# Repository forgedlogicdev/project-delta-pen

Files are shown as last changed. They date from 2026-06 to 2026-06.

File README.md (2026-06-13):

# Project Delta Pen (DP-1)
> **STATUS: ACTIVE R&D**  
> High-precision, ergonomic, motorized coaxial TIG filler wire feeder powered by RP2040 and closed-loop force sensing feedback.

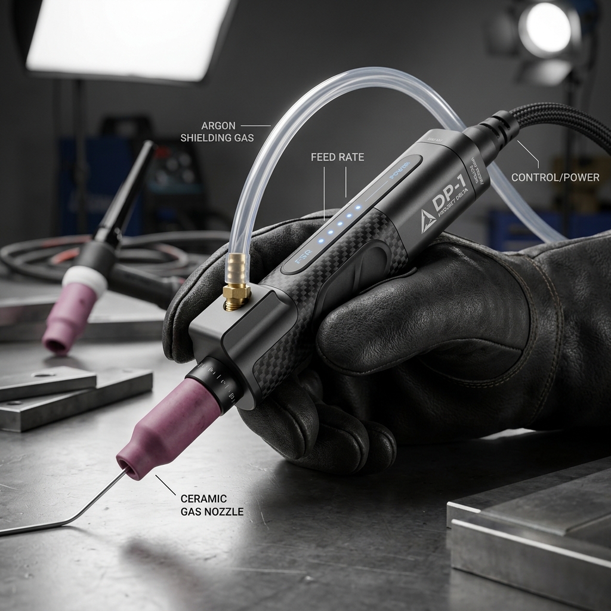
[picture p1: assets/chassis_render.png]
Project Delta Pen (DP-1) Mockup


---

## System Overview

Project Delta Pen (DP-1) is a handheld, motorized welding wire feeder designed to streamline TIG wire deposition. Featuring a lightweight, coaxial wire feed path and an integrated Force Sensitive Resistor (FSR) index grip, the DP-1 responds dynamically to user finger pressure, outputting precise wire feed rates directly into the weld puddle.

```mermaid
graph LR
    User(["User Finger Force"]) -->|Pressure| FSR["FSR Strip GPIO 26"]
    FSR -->|Analog Signal| MCU["RP2040 Microcontroller"]
    Switch["Pulse-Dab Switch GPIO 15"] -->|Hardware Interrupt| MCU
    MCU -->|PWM/Pulse| Driver["TMC2209 Driver"]
    Driver -->|Torque| Motor["NEMA 8 Motor"]
    Motor -->|Direct Drive| Pinch["Pinch Wheel Mechanism"]
    Pinch -->|Coaxial Path| Wire["TIG Filler Wire"]
```

---

## Directory Structure

```text
peaceful-franklin/
├── .gitattributes          # LFS tracking configurations
├── .gitignore              # Dependency and build exclusions
├── LICENSE                 # MIT Open Source License
├── README.md               # High-level architecture and mechanical logic
├── BUILD.md                # Component sourcing and assembly guide
├── docs/                   # Detailed technical breakdowns
│   ├── specs.md            # Hardware tolerances and power curves
│   └── user_manual.md      # Calibrations and operation guide
├── cad/                    # Parametric CAD models
│   ├── chassis.scad        # Ergonomic handheld shell design
│   └── drive_gear.scad     # V-groove pinch wheel models
├── firmware/               # Microcontroller firmware
│   └── main.py             # CircuitPython RP2040 control loop
└── assets/                 # Schematics and visual guides
    ├── chassis_render.png  # High-fidelity industrial design mockup
    └── connection_map.png  # Wiring diagrams
```

---

## Mechanical Logic

The DP-1's mechanical efficiency relies on two primary innovations: its **coaxial wire feed path** and the **direct-drive pinch mechanism**.

```
             [ NEMA 8 Motor ]
                   │
                   ▼ (Direct Drive shaft)
           [ V-Groove Wheel ] <--- (Pinch Force) ---> [ Bearing Tensioner ]
                   │
                   ▼
===================[ Coaxial Wire Feed Guide Tube ]===================
==== Wire ==========================================================>
```

### 1. Coaxial Wire Feed
Traditional motorized wire feeders feed wire off-axis, creating rotational torque that causes hand fatigue during long welding runs. The DP-1 routes the filler wire directly through the centerline axis of the pen-like body. The wire exits the rear, travels through a flexible PTFE guide sheath, passes through the motor chassis, and exits straight out of the nozzle. This eliminates off-axis drag and maintains optimal ergonomics.

### 2. Direct-Drive Pinch Mechanism
To feed 1.6mm to 3.2mm aluminum or stainless steel wire without slipping, the chassis houses a high-torque **NEMA 8 stepper motor** mated to a custom-grooved **V-Groove drive wheel**. A secondary spring-loaded guide bearing pinches the wire against the V-groove. This direct coupling ensures zero backlash, high driving torque, and instant startup/stop response.

---

## Firmware Overview

The system runs a modular control loop implemented in CircuitPython on the RP2040. Features include:
* **Dynamic FSR Scaling**: Analog pressure mapping to feed rate.
* **Safety Pulse-Dab Switch**: Dedicated GPIO hardware interrupt to pause, retract, or pulse feed instantly, preventing runaway feeding.

For source details, see [firmware/main.py](file:///home/_____/Documents/antigravity/peaceful-franklin/firmware/main.py).

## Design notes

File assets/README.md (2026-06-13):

# Project Delta Pen Assets Directory
This folder contains graphical resources, wiring diagrams, and high-resolution schematics for the DP-1 hardware.

## Expected Files
* `connection_map.png`: Main RP2040 and TMC2209 wiring schematic.
* `chassis_render.png`: 3D-render of the assembled coaxial handle shell.

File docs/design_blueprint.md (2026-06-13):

# Project Delta Pen (DP-1) Engineering & Design Blueprint
> **Version**: 1.1.0  
> **Classification**: Technical Design Proposal / R&D Guide  
> **Authors**: Lead Systems Architect & Engineering Team  

This document serves as the high-level structural, mechanical, and electrical blueprint for the **Project Delta Pen (DP-1)**. It addresses the engineering challenges of miniaturized, coaxial wire-feeding, structural thermodynamics, and force-sensitive control loops.

---

## 1. Ergonomic & Structural Architecture

The primary design challenge of the DP-1 is maintaining hand comfort over long duty cycles while carrying an active actuator (NEMA 8 stepper motor).

```
                     [ CENTER OF MASS ]
                             ▼
  ┌───────────────────────────────────┬──────────────┐
  │         ERGO GRIP SECTION         │ MOTOR BLOCK  │ ===> Rear Harness
  │  (Lightweight SLS Nylon / Carbon) │ (6061 Alum)  │      (Power & Gas)
  └───────────────────────────────────┴──────────────┘
  ◄────────────── 100mm ─────────────►◄──── 20mm ────►
```

### Material Selection Comparison
We evaluated three primary fabrication paths for the pen housing:

| Fabrication Method | Recommended Materials | Tensile Strength | Thermal Conductivity | Pro/Con Analysis |
|---|---|---|---|---|
| **SLS 3D Printing (Recommended)** | Nylon PA12 / Carbon-Filled | ~48 MPa | Low (~0.25 W/m·K) | **Pros**: Excellent weight distribution, complex internal wire routing. <br>**Cons**: Poor heat dissipation. |
| **CNC Machining** | 6061-T6 Anodized Aluminum | ~310 MPa | High (~167 W/m·K) | **Pros**: Extreme durability, acts as a heatsink. <br>**Cons**: Increases hand weight (fatigue), requires electrical isolation. |
| **FDM 3D Printing** | PETG / Polycarbonate (PC) | ~60 MPa | Low | **Pros**: Fast prototyping, low cost. <br>**Cons**: Anisotropic strength (weak layer bonding under wire tension). |

### Engineering Decision
* **Chassis Body**: Select **SLS Nylon PA12** for its structural density, toughness, and thermal isolation from the welding environment.
* **Motor & Tension Block**: Select CNC machined **6061-T6 Aluminum**. This block mounts directly to the NEMA 8 motor to act as a heat-sink, protecting the user's hand from motor-coil heat.

---

## 2. Mechanical Drive & Torque Physics

Feeding rigid filler wire (such as 2.4mm ER70S-6 steel or ER4043 aluminum) requires significant linear push force without buckling or crushing the wire.

```
       Force (Idler Pressure)
              │
              ▼
   [ U-Groove Idler Bearing ]
  ═════════════════════════════  ◄─── Filler Wire
   [ V-Groove Drive Gear ]
              ▲
              │
         Motor Torque
```

### Torque Calculations
To calculate the minimum holding torque required for the stepper motor ($T_{motor}$):
$$T_{motor} = F_{push} \times r_{drive}$$

Where:
* $F_{push}$ = Linear force required to feed wire through the PTFE tube (typically 12 N to 20 N depending on bends).
* $r_{drive}$ = Radius of the drive wheel ($6\text{ mm} = 0.006\text{ m}$).

$$T_{motor} = 20\text{ N} \times 0.006\text{ m} = 0.12\text{ N·m} = 12\text{ N·cm}$$

* **Motor Specification**: A standard NEMA 8 stepper motor (e.g., 20mm body) provides approximately $1.6\text{ to }3.0\text{ N·cm}$ holding torque. This is **insufficient** for direct drive under heavy friction.
* **Solution**: 
  1. Use a **geared NEMA 8** (e.g., 5:1 planetary gearbox) to multiply torque to $15\text{ N·cm}$ while maintaining low weight.
  2. Implement ultra-low friction **polished PTFE liners** (1.8mm ID for 1.6mm wire) to keep $F_{push}$ under $4\text{ N}$, which keeps direct drive viable.

---

## 3. Electronics & Driver Configuration

The **TMC2209** stepper driver must be software-configured via UART or physical hardware pins to balance noise, heat, and torque.

### StealthChop™ vs. SpreadCycle™
* **StealthChop (Quiet)**: Reduces motor noise to near silent. However, high-current peaks can cause step losses when the filler wire encounters friction.
* **SpreadCycle (High Torque)**: Offers superior torque dynamics and speed control, but introduces standard stepper motor whine.
* **Hybrid Configuration (Recommended)**: Set the threshold velocity in firmware. Below 20 mm/s (normal welding speeds), run StealthChop for silent operation. Above 20 mm/s, transition to SpreadCycle for peak driving torque.

### Thermal Dissipation
Operating a NEMA 8 motor close to its current limit (0.6A) inside a hand-held plastic pen causes heat accumulation. 
* Set motor current limit ($I_{rms}$) to **70% of rated capacity** ($0.4A$) in the driver settings.
* Implement an auto-standby power down: if the FSR has not registered force for 5 seconds, cut driver coil current to **10%** to prevent pen heat buildup.

---

## 4. Force-Sensitive Control Loop

A simple linear mapping of pressure to speed results in jerky wire feeding. The control loop must implement smoothing and threshold curves.

```
 Feed Rate (mm/s)
   │
120│                                  / (Exponential ramp)
   │                                 /
   │                                /
   │                       ________/
  0│───────────────────────
   └───[Deadzone]───────────► FSR ADC Value (0-65535)
     0 - 8000            60000
```

### Proportional-Derivative (PD) Signal Smoothing
The firmware reads the FSR ADC value and processes it using a low-pass filter (Exponential Moving Average) to prevent jitter:

$$V_{smooth} = \alpha \cdot V_{raw} + (1 - \alpha) \cdot V_{prev}$$

Where $\alpha = 0.15$ provides clean damping without noticeable input lag.

### Safety State Machine
The safety interrupt must follow a strict non-blocking hardware design:

```
  ┌──────────────┐      FSR Squeezed      ┌──────────────┐
  │  Idle State  ├───────────────────────►│ Feeding State│
  └──────▲───────┘                        └──────┬───────┘
         │                                       │
         │          Pulse-Dab Pressed            │
         └───────────────────────────────────────┘
```
When the `Pulse-Dab` switch is closed (pull-up pulled low), the RP2040 triggers an immediate interrupt, disabling the `EN` pin of the TMC2209 and ignoring FSR values until the switch is reset.

---

## 5. Welding Gas & Arc Integration

Shielding gas (Argon) must flow coaxially to shield the weld puddle from atmospheric contamination.

* **Gas Seal**: The shielding gas channel runs parallel to the wire feeding channel. It exits through internal gas diffusers in the front housing to create laminar flow.
* **Heat Shielding**: The ceramic gas cup (typically Size 6 or 8) is threaded onto a custom brass gas lens adapter. This lens isolates the printed plastic pen chassis from the high heat of the tungsten electrode.

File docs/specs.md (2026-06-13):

# Project Delta Pen (DP-1) Technical Specifications
> **Revision: 1.0.2**

This document details the engineering limits, electrical characteristics, and force sensor curves for the DP-1.

---

## 1. Physical Dimensions & Weights
* **Total Length (Chassis Only)**: 120 mm
* **Grip Diameter**: 14 mm to 18 mm (ergonomic taper)
* **Dry Weight**: 85g (excluding cable harness and stepper motor)
* **Total Operating Weight**: 142g (with NEMA 8 motor attached)

---

## 2. Stepper Actuation Parameters
* **Motor Type**: NEMA 8 Stepper (Dual Phase, bipolar)
* **Rated Current**: 0.6A per phase
* **Step Angle**: 1.8° per step (200 full steps per revolution)
* **Microstepping**: 1/16 microstepping configured on TMC2209 driver (3200 steps/rev)
* **Wire Feed Velocity Range**: 5 mm/s to 120 mm/s (controlled dynamically via FSR)

---

## 3. FSR Pressure Mapping Curve
The Interlink FSR 402 strip input is read through a 10-bit or 12-bit ADC on the RP2040. The force response follows an exponential curve:

| Applied Force (N) | Resistance (Ω) | ADC Voltage (V, 3.3V Ref) | Feed Rate (mm/s) |
|---|---|---|---|
| < 0.2 N | > 1 MΩ (Open) | < 0.15 V | 0 (Idle) |
| 0.5 N | ~ 10 kΩ | ~ 1.10 V | 10 mm/s |
| 2.0 N | ~ 2 kΩ | ~ 2.50 V | 45 mm/s |
| > 10.0 N | < 1 kΩ (Sat) | ~ 3.10 V | 120 mm/s |

---

## 4. Electrical Connections

```
    [RP2040 GPIO]                     [TMC2209 Driver]
    GP2 (Step) ──────────────────────► STEP
    GP3 (Dir)  ──────────────────────► DIR
    GP4 (En)   ──────────────────────► EN (Active Low)
    3.3V OUT   ───────┬──────────────► VDD (Logic)
                      │
                   [FSR]
                      │
    GP26 (ADC0) ◄─────┴───[10kΩ Pulldown]───► GND
```

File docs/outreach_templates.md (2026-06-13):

# Project Delta Pen (DP-1) Outreach Email Templates
> **Classification: External Communication & Marketing Briefs**

This document tracks outreach templates (in both plain text and styled HTML format) used for pitching the DP-1 technology.

---

## 1. Styled HTML Templates
HTML files are fully styled with embedded images, buttons, and custom layout tables:

*   **[docs/adafruit_pitch.html](file:///home/_____/Documents/antigravity/peaceful-franklin/docs/adafruit_pitch.html)**: Styled pitch for Adafruit featuring the RP2040 Silicon and CircuitPython stack.
*   **[docs/ck_pitch.html](file:///home/_____/Documents/antigravity/peaceful-franklin/docs/ck_pitch.html)**: Styled B2B proposal for CK Worldwide featuring the physical mockup render and engineering specifications.

---

## 2. Plain Text Outreach Emails

### Pitch 1: Adafruit (support@adafruit.com)
```text
Subject: Project Showcase: Motorized Coaxial TIG Welding Pen (Powered by RP2040 & CircuitPython)

Hi Adafruit Team,

I wanted to share a project I've been developing that applies Adafruit's favorite ecosystem—the RP2040 and CircuitPython—directly to industrial metal fabrication. 

It’s called Project Delta Pen (DP-1): an ergonomic, motorized coaxial TIG welding wire feeder. 

The pen uses an FSR strip on the index grip to dynamically map finger force to stepper motor feed speed, letting welders deposit filler metal with high precision. It is driven by a TMC2209 silent stepper driver and is powered entirely by CircuitPython on the RP2040. 

I’ve engineered a safety halt state machine using hardware interrupts on the RP2040 to guarantee instant feed stops, preventing wire overrun in industrial conditions.

Here is the GitHub repository detailing the OpenSCAD chassis files, build sheets, and current control loop:
https://github.com/forgedlogicdev/project-delta-pen

I’d love to know if this is something you would be interested in featuring on the Adafruit blog, or if you'd be open to a quick chat about optimizing FSR input conditioning.

Best regards,
ForgedLogic
```

### Pitch 2: CK Worldwide (tech@ckworldwide.com)
```text
Subject: Technical Proposal: Integrated Coaxial Motorized Wire Feeder Retrofit for TIG Torches

Dear CK Worldwide Technical Team,

As a manufacturer of industry-leading TIG welding equipment, you are well-aware of the primary ergonomic bottlenecks in manual TIG welding: hand fatigue, rotational torque from off-axis wire feeding, and deposit consistency over long duty cycles.

To address this, we have prototyped the Project Delta Pen (DP-1), a lightweight, motorized coaxial TIG wire feeder that mounts directly inline with the torch axis. 

By routing the filler wire coaxially through the centerline axis of the pen-like modifier, we eliminate off-axis drag and rotational torque. The device is powered by an embedded RP2040 microcontroller and driven by a micro-stepper motor mated to a hardened V-groove pinch wheel. It utilizes a Force Sensitive Resistor (FSR) strip along the index grip, allowing the operator to dynamically adjust the feed rate (0 to 120 mm/s) with simple finger pressure.

We have published our high-level mechanical design blueprint and initial specifications here:
https://github.com/forgedlogicdev/project-delta-pen/blob/main/docs/design_blueprint.md

We believe this concept represents a significant leap forward in automated/semi-automated TIG ergonomics. We would be eager to share our CAD files, engineering parameters, and prototype performance data with your engineering team, or set up a brief technical call to discuss potential collaboration.

Sincerely,
ForgedLogic
```

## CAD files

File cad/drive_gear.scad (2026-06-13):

// Project Delta Pen (DP-1) - V-Groove Stepper Drive Gear
// Designed to clamp onto a 5mm NEMA 8 stepper shaft and grip TIG filler wire.

$fn = 80;

gear_diameter = 12;
gear_thickness = 8;
bore_diameter = 5.0; // standard motor shaft
groove_depth = 1.0;
groove_angle = 90; // 90 degree V-groove

module drive_gear() {
    difference() {
        // Outer wheel body
        cylinder(h=gear_thickness, d=gear_diameter, center=true);
        
        // Motor shaft bore
        cylinder(h=gear_thickness + 2, d=bore_diameter, center=true);
        
        // V-Groove path for the wire
        rotate_extrude() {
            translate([gear_diameter/2, 0, 0])
                rotate([0, 0, 45])
                    square([groove_depth * sqrt(2), groove_depth * sqrt(2)], center=true);
        }
        
        // Set screw M3 thread hole
        translate([0, 0, 0])
            rotate([90, 0, 0])
                cylinder(h=gear_diameter + 2, d=2.5, center=true);
    }
}

drive_gear();

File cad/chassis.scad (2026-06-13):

// Project Delta Pen (DP-1) - Ergonomic Handheld Chassis
// Tolerances and variables optimized for FSR strip insertion and NEMA 8 motor alignment.

$fn = 100;

// Pen dimensions
pen_length = 120;
pen_diameter = 18;
grip_taper = 14;

// Motor mounting base
motor_width = 20.5; // NEMA 8
motor_hole_spacing = 16.0;

module main_chassis() {
    difference() {
        // Main cylindrical handle
        union() {
            cylinder(h=pen_length - 20, d=pen_diameter, center=true);
            translate([0, 0, (pen_length/2) - 10])
                cylinder(h=20, d1=pen_diameter, d2=grip_taper, center=true);
        }
        
        // Coaxial wire feed guide channel (3mm PTFE path)
        cylinder(h=pen_length + 2, d=3.2, center=true);
        
        // FSR Sensor Recess (1mm deep indentation for flush fit)
        translate([0, (pen_diameter/2) - 0.5, 10])
            cube([6, 1.2, 50], center=true);
    }
}

main_chassis();

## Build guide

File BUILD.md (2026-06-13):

# BUILD.md: Project Delta Pen Assembly Guide
> **Model: DP-1**  
> **Precision Level: Toolroom/R&D**

This guide covers the step-by-step physical assembly of the Delta Pen housing, driving components, and electronic sensors.

---

## Bill of Materials (BOM)

### 1. Actuation & Drive
* **Motor**: NEMA 8 Stepper Motor (20mm length, 1.8° step angle).
* **Drive Wheel**: Hardened steel V-Groove wheel (5mm bore, matching wire gauge).
* **Idler**: Ball-bearing U-groove pressure wheel.
* **Tensioner**: M3 steel adjustment thumb screw with compression spring.

### 2. Sensors & Electronics
* **Microcontroller**: RP2040 (e.g., Raspberry Pi Pico or Qt Py RP2040).
* **Driver**: TMC2209 StepStick module.
* **Force Sensor**: Interlink FSR 402 strip (or equivalent analog force-sensitive resistor).
* **Interrupt Switch**: SPST momentary micro-switch (Pulse-Dab Switch).

---

## Assembly Sequence

### Step 1: Drive Assembly Prep
1. Press-fit the **V-groove drive wheel** onto the NEMA 8 stepper motor shaft.
2. Align the groove with the central axis line of the motor faceplate.
3. Torque the M3 grub screws on the drive wheel to **0.6 N·m** using a hex key.

### Step 2: Idler Tensioner Mounting
1. Mount the spring-loaded idler arm onto the CAD-printed chassis base.
2. Insert the compression spring and secure the M3 thumb screw through the tensioner block.
3. Verify the idler arm moves freely without binding.

### Step 3: Coaxial Path Alignment
1. Thread the **PTFE liner** (inner diameter matching the wire size + 0.2mm) through the rear entry channel of the pen chassis.
2. Position the exit nozzle guide within **2.0 mm** of the V-groove pinch zone to prevent the filler wire from buckling under load.

### Step 4: FSR Strip Placement
1. Adhere the **FSR sensor strip** along the ergonomic index finger indentation on the chassis exterior.
2. Route the flexible tail through the chassis internal cable channel to the RP2040 compartment.
3. Ensure no sharp plastic edges bend the sensor tail.

### Step 5: Wiring & Controller Integration
1. Solder the FSR sensor to a voltage divider circuit (10kΩ pulldown resistor to ground, analog terminal to RP2040 **GP26/ADC0**).
2. Wire the pulse-dab switch to **GPIO 15** (internal pull-up enabled).
3. Connect the step/dir interface to the TMC2209 driver board according to the pin configuration.

---

## Validation & Calibration

Before powering on the motor driver, perform the following mechanical checks:
* **Friction Check**: Feed a length of wire manually by turning the motor shaft. There should be uniform friction and no slippage.
* **Tension Adjustment**: Tighten the M3 tensioner thumb screw until the wire feeds against slight hand resistance, then tighten another half-turn. Do not overtighten to avoid flattening soft filler wires (like aluminum).

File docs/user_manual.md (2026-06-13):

# Project Delta Pen (DP-1) User Operation Manual

A practical reference manual for operators using the DP-1 motorized TIG wire feeder in production environments.

---

## 1. Initial Setup
1. Feed the TIG filler wire into the rear PTFE sheath until it interfaces with the V-Groove drive wheel inside the pen assembly.
2. Hold down the **Pulse-Dab Switch** (safety halt) while threading the wire past the drive wheel to prevent manual gear damage.
3. Release the switch once the wire emerges from the copper contact nozzle tip at the front of the pen.
4. Adjust the idler tension thumb screw until the wire is held securely in the V-groove.

---

## 2. Operation Modes

### Grip Force Feed Mode (FSR Control)
* **Start Feeding**: Apply gentle squeeze pressure to the FSR sensor strip on the grip section.
* **Variable Velocity**: Increase squeeze force to speed up the feed rate (ranges from fine dabbing to continuous high-speed deposition).
* **Stop Feeding**: Release finger pressure. The controller immediately stops step pulses.

### Pulse-Dab Switch Interaction (GPIO 15)
* **Instant Pause**: Pressing the Pulse-Dab switch acts as an asynchronous hardware-level interrupt. All stepping stops instantly, and the motor driver coil power is cut to allow manual wire slippage or adjustment.
* **Emergency Halt**: In the event of a sticking wire, pressing this switch disables the stepper outputs.

---

## 3. Calibration Procedures
If the wire feeds too slowly or fails to start at low finger force, adjust the ADC noise floor parameters in [firmware/main.py](file:///home/_____/Documents/antigravity/peaceful-franklin/firmware/main.py):

* **`ADC_MIN_THRESHOLD`**: Lower this value if you have light touch or smaller fingers. Increase it if resting your finger triggers unwanted feeding.
* **`MIN_DELAY_US` / `MAX_DELAY_US`**: Modify these step delays to tune minimum/maximum wire speed to match your welding current.

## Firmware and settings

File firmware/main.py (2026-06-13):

import time
import board
import digitalio
import analogio

# ==========================================
# PIN CONFIGURATION (RP2040)
# ==========================================
# Stepper driver interface (TMC2209)
STEP_PIN = board.GP2
DIR_PIN = board.GP3
EN_PIN = board.GP4

# Sensors and User Input
FSR_PIN = board.GP26          # ADC0
PULSE_DAB_PIN = board.GP15    # Digital Interrupt Switch

# ==========================================
# HARDWARE INITIALIZATION
# ==========================================
# Stepper Outputs
step_out = digitalio.DigitalInOut(STEP_PIN)
step_out.direction = digitalio.Direction.OUTPUT

dir_out = digitalio.DigitalInOut(DIR_PIN)
dir_out.direction = digitalio.Direction.OUTPUT

en_out = digitalio.DigitalInOut(EN_PIN)
en_out.direction = digitalio.Direction.OUTPUT
en_out.value = True  # Start disabled (Active Low)

# Analog Input (Force Sensitive Resistor)
fsr_in = analogio.AnalogIn(FSR_PIN)

# Safety Pulse-Dab Switch (Normally open, pull-up triggers on press)
dab_switch = digitalio.DigitalInOut(PULSE_DAB_PIN)
dab_switch.direction = digitalio.Direction.INPUT
dab_switch.pull = digitalio.Pull.UP

# ==========================================
# PARAMETERS & CALIBRATION
# ==========================================
ADC_MIN_THRESHOLD = 5000   # Noise deadzone threshold (out of 65535)
ADC_MAX_LIMIT = 60000       # Max force saturation threshold
MIN_DELAY_US = 200          # Fast speed delay (lower is faster)
MAX_DELAY_US = 5000         # Slow speed delay (higher is slower)

# ==========================================
# UTILITY & DRIVER LOGIC
# ==========================================
def map_value(val, in_min, in_max, out_min, out_max):
    """Linearly maps a value from one range to another."""
    if val <= in_min:
        return out_max
    if val >= in_max:
        return out_min
    return out_min + (val - in_min) * (out_max - out_min) / (in_max - in_min)

def execute_step():
    """Generates a single step pulse to the TMC2209 driver."""
    step_out.value = True
    time.sleep_seconds(0.000002)  # 2 microsecond step pulse high
    step_out.value = False

# ==========================================
# MAIN EXECUTION LOOP
# ==========================================
print("DP-1 Control Firmware initialized.")
en_out.value = False  # Enable motor outputs

while True:
    # --- Safety Interrupt Check ---
    # The Pulse-Dab switch acts as an immediate safety pause or pulse activator.
    # If the switch is pressed (reading Low due to pull-up), halt motor operation.
    if not dab_switch.value:
        en_out.value = True  # Cut power to motor coils (coast)
        print("[SAFETY] Pulse-Dab switch pressed. Motion paused.")
        
        # Debounce/wait until released
        while not dab_switch.value:
            time.sleep(0.05)
            
        en_out.value = False  # Re-enable motor
        print("[SAFETY] System armed. Resuming operation.")
        continue

    # --- Read Grip Pressure (FSR) ---
    raw_force = fsr_in.value
    
    # --- Motor Feed Logic ---
    if raw_force > ADC_MIN_THRESHOLD:
        dir_out.value = True  # Feed forward
        
        # Map analog force directly to dynamic step frequency
        step_delay = map_value(raw_force, ADC_MIN_THRESHOLD, ADC_MAX_LIMIT, MIN_DELAY_US, MAX_DELAY_US)
        
        # Execute feed step
        execute_step()
        
        # Delay between steps (CircuitPython sleep)
        time.sleep(step_delay / 1000000.0)
    else:
        # Idle state - wait briefly to avoid spinning CPU cycles
        time.sleep(0.01)

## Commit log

2026-06-13 feat: bootstrap Project Delta Pen DP-1 architecture
    [chassis.scad, drive_gear.scad]
2026-06-13 design: add industrial design render of the DP-1 chassis showing the gas line
2026-06-13 docs: add comprehensive engineering design blueprint and torque math
